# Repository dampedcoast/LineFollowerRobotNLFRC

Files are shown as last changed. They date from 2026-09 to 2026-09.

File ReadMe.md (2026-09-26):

# PD Line Follower — ESP32-S3 · XLine 16 · N20

A competition line-following robot built on an **ESP32-S3**, an **XLine 16** analog IR sensor
array and two **N20 gear motors 5volts 1000 RPM** with tb6612 motor driver. It runs a PD controller with a sensor-driven state machine
for forks, acute tips, 90° corners, zigzags, inverted (white-on-black) zones, line gaps and a
full-black finish pad.

Every tuning parameter can be changed **live over Wi-Fi** from a phone. No reflashing is needed
between runs.

---

## Table of Contents
- [Features](#features)
- [Hardware](#hardware)
- [Wiring](#wiring)
- [Sensor Layout](#sensor-layout)
- [Software Setup](#software-setup)
- [Web Tuner](#web-tuner)
- [First-Run Calibration](#first-run-calibration)
- [How It Works](#how-it-works)
- [Telemetry States](#telemetry-states)
- [Parameter Reference](#parameter-reference)
- [Tuning Guide](#tuning-guide)
- [Troubleshooting](#troubleshooting)
- [Revision History](#revision-history)
- [License](#license)

---

## Features

- **PD steering** on a squared-weight centroid, measured in channel units (error −7 … +7)
- **Straight-line boost**: extra speed when centered, normal speed while correcting
- **Error-hold**: keeps steering with the last correction when the line slides off the side
- **Edge-latch routing**: the outer sensors detect a branch *before* the line is lost, then the
  robot pivots toward the latched side (acute tips, diodes, 90° corners)
- **Sticky Y-bias**: wide clusters commit to one edge until the line narrows again
- **Fork selection** with position continuity (ignores far-away line jumps)
- **Inverted-zone detection**: automatic polarity flip on entry and exit
- **Zone-gap window**: after leaving an inverted zone, a missing line triggers a forward probe instead of reversing
- **Lost-line recovery**: forward gap probe, then reverse until the center sensor is on the line, then spin at the vertex
- **Zigzag mode**: detects rapid alternating corners and drops the base speed
- **Kick-start** on motor direction changes to overcome N20 static friction
- **Full-black finish pad** detection with automatic stop
- **Live web UI** with a sensor bar, state, polarity, edge latches, PWM output and loop timing

---

## Hardware

| Component | Details |
|---|---|
| MCU | ESP32-S3 dev board |
| Line sensor | XLine 16 IR array: 16 channels behind a 16:1 analog multiplexer (S0–S3 select, one analog output) |
| Motors | 2 × N20 micro gear motors (`5 volts 1000 RPM`) |
| Motor driver | tb6612 drive motor driver |
| Power | 12 Volts Lipo 1300mAH with a buck converter for a 5volts output |
| Start button | Momentary push button to GND (uses the internal pull-up) |

---

## Wiring

### Motor driver

| Driver pin | ESP32-S3 GPIO | Function |
|---|---|---|
| IN1 | 6 | Left motor direction A |
| IN2 | 7 | Left motor direction B |
| ENA | 9 | Left motor PWM (1 kHz, 8-bit) |
| IN3 | 4 | Right motor direction A |
| IN4 | 5 | Right motor direction B |
| ENB | 8 | Right motor PWM (1 kHz, 8-bit) |

> If a motor spins backwards, swap its two motor wires on the driver output. There is no need to change the code.

### XLine 16 sensor

| XLine 16 pin | ESP32-S3 GPIO | Function |
|---|---|---|
| S0 | 10 | Mux select bit 0 |
| S1 | 11 | Mux select bit 1 |
| S2 | 12 | Mux select bit 2 |
| S3 | 13 | Mux select bit 3 |
| SIG / OUT | 2 | Analog output (ADC, 11 dB attenuation, 0–4095) |
| VCC / GND | 3V3 / GND | Power |

### Other

| Part | GPIO |
|---|---|
| Start/stop button | 1 (to GND, `INPUT_PULLUP`) |

---

## Sensor Layout

```
        LEFT                                        RIGHT
  [14][13][12][11][10][ 9][ 8][ 7][ 6][ 5][ 4][ 3][ 2][ 1][ 0]
   ^^^^^^                                              ^^^^^^
   left edge zone                                right edge zone
                         center = 7.0

  CH15 = center / pivot-axis sensor (read separately)
```

- Channels **0–14** form the tracking bar. **Index 0 is the rightmost** and 14 is the leftmost.
- `error > 0` means the line is to the **left**.
- The outer `EDGE_ZONE` channels on each side act as edge-latch detectors. **Keep all 15 active.**
- **CH15** sits at the robot's pivot axis. Lost-line recovery reverses until CH15 is on the
  line, so the recovery spin happens exactly at the vertex of an acute tip.

---

## Software Setup

1. Install the **Arduino IDE** (2.x recommended).
2. Add the **ESP32 board package, version 3.x**. The code uses the 3.x `ledcAttach()` API and will not compile on 2.x.
3. Select your ESP32-S3 board and port.
4. Open `line_follower/line_follower.ino` and upload.

No external libraries are needed. `WiFi.h` and `WebServer.h` ship with the ESP32 core.

---

## Web Tuner

1. Power on the robot.
2. Connect your phone or laptop to Wi-Fi **`LineFollower`** (password `12345678`).
3. Open **http://192.168.4.1**.

The page refreshes every 300 ms and shows:

| Field | Meaning |
|---|---|
| Sensor bar | `B` = on the line, `W` = background (polarity-aware) |
| State | Current control state (see [Telemetry States](#telemetry-states)) |
| Status | ON LINE / LOST / FINISHED |
| Polarity | normal / INVERTED |
| Line count / clusters | Active channels / significant clusters |
| Max cluster width | Widest cluster in channels |
| Edge latch L/R | Currently latched branch sides |
| Route side / event | Side the router will pick, and whether a fork event is locked |
| Track pos | Current tracked line position (0–14) |
| Center CH15 | Pivot-axis sensor state |
| Error / Corr | PD error and correction |
| L / R PWM | Motor commands (−255 … 255) |
| Loop µs (max) | Control loop timing |

Every parameter has an input box. Changes apply **immediately** but are **not saved to flash**.
They reset to the code defaults on reboot, so copy any good values back into the code.

Press **START** on the page or the physical button to run or stop. Each start resets all runtime state.

---

## First-Run Calibration

Do these on the actual mat before the first timed run:

1. **`THRESHOLD` / `NOISE`**: place the bar over white, then over the black line, and read
   the raw values. Set `THRESHOLD` between them and `NOISE` just above the white reading.
2. **`INV_WHITE`**: park the bar **inside an inverted zone** and read the raw values of the white line
   on black. Set `INV_WHITE` between the white-line and black-background readings.
3. **Direction check**: run slowly (`base` ≈ 80) and confirm that a line on the left makes the robot
   turn left. If it turns the wrong way, swap the motor wires. Do not flip signs in the code.
4. **`Y_SIDE`**: set the default fork preference (1 = left, 2 = right, 0 = nearest).

---

## How It Works

Each loop (about 4 ms plus sensor read time), `control()` runs through these stages in priority
order. The first stage that takes control returns.

| # | Stage | What it does |
|---|---|---|
| 0 | Edge scan | Every cycle: latches a side if an outer edge sensor sees line while the main line is centered |
| 1 | Black-back | Reverses off the finish pad (only if `FULL_BLACK_STOP = 0`) |
| 2 | Inverted probe | After an all-line event, drives straight to decide between a zone entry and the finish pad |
| 3 | Pivot | Continues an in-place corner pivot until the line is near center |
| 4 | Edge turn | Continues a latched-side pivot until the line overshoots center, then hands back to PD |
| 5 | All-line | Crossing blip (`XING`), or confirmed zone entry/exit (`INV?` / `INV-OUT`) |
| 6 | Edge-turn trigger | Line lost with a fresh latch: start an edge turn |
| 7 | Line lost | Zone-gap probe → error-hold → gap probe → reverse to vertex → spin search |
| 8 | Target selection | Chooses a cluster by continuity, fork side, or sticky Y-bias edge |
| 9 | Pivot entry | A large error starts a corner pivot and counts toward zigzag mode |
| 10 | PD | `corr = Kp·e + Kd·(e − e_last)`, with boost and a reverse limit |

### Routing priority (which way to turn)

1. **Zone-gap window active**: no turn, drive forward
2. **Freshest edge latch**: the side that was just seen branching
3. **Event-held side**: the side locked when the fork event opened
4. **`Y_SIDE`** fallback, or the last-seen line position during spin recovery

There is no hardcoded turn sequence. Every routing decision comes from the sensors.

---

## Telemetry States

| State | Meaning |
|---|---|
| `stopped` | Not running |
| `PD` / `PD-ZZ` | Normal tracking / tracking in zigzag mode |
| `FORK` | Two candidate lines, picking by route side |
| `Y-BIAS` | Hugging one edge of a wide cluster |
| `SNAP-TURN` | Both lines visible with center on: boosted gains |
| `CORNER_L/R`, `ZZ_L/R` | In-place pivot (normal / zigzag) |
| `EDGE_L/R` | Edge-latch turn in progress |
| `XING` | Crossing or checkpoint bar being ridden through |
| `INV?` | All-line confirmed, probing: zone or finish? |
| `INV-IN` | Entered an inverted zone |
| `INV-OUT` | Left an inverted zone |
| `ZONE-GAP` | Expected gap after a zone exit, driving forward |
| `ERR-HOLD` | Line slid off the side, holding the last correction |
| `GAP-FWD` | Centered line vanished, probing forward for a gap |
| `LOST-BACK` | Reversing until CH15 finds the line |
| `LOST-SPIN` / `LOST-FWD` | Spinning / creeping forward to reacquire |
| `BLACK-BACK` | Reversing off the finish pad |
| `FINISH` | Finish pad confirmed, motors stopped |

---

## Parameter Reference

All parameters are live-tunable from the web UI. Distances and positions are in **channel units** (0–14).

### PD and speed
| Param | Default | Description |
|---|---|---|
| `Kp` | 40.0 | Proportional gain |
| `Kd` | 165.0 | Derivative gain |
| `base` | 150 | Base PWM |
| `BOOST_XP` | 30 | Extra PWM when centered (0 = off) |
| `BOOST_BAND` | 0.5 | Error range that counts as centered |
| `SPEED_LIMIT` | 255 | Maximum forward PWM |
| `MAX_REVERSE` | 255 | Maximum reverse PWM (scaled with the effective base) |
| `ERR_HOLD_MS` | 250 | How long to hold the last correction after a side loss |

### Sensors
| Param | Default | Description |
|---|---|---|
| `THRESHOLD` | 1800 | Raw value above which a channel is on the black line |
| `NOISE` | 1000 | Raw floor subtracted before weighting |
| `MUX_SETTLE_US` | 60 | Settling delay after switching mux channels |

### Pivot and zigzag
| Param | Default | Description |
|---|---|---|
| `PIVOT_THRESHOLD` | 5.0 | Error that triggers an in-place pivot |
| `PIVOT_SPEED` | 90 | Pivot PWM |
| `PIVOT_TIMEOUT_MS` | 900 | Pivot give-up time |
| `ZZ_BASE` | 110 | Base PWM in zigzag mode |
| `ZZ_TRIGGER` | 2 | Corners within the window that enable zigzag mode |
| `ZZ_WINDOW_MS` | 150 | Corner-streak window |
| `ZZ_EXIT_MS` | 75 | Leave zigzag mode after this long without a corner |
| `ZZ_CENTER_MS` | 75 | …or after this long centered |

### Inverted zones and crossings
| Param | Default | Description |
|---|---|---|
| `INV_WHITE` | 1800 | Raw value below which a channel is on the white line (inverted). **Calibrate on the mat** |
| `XING_MIN` | 8 | Active channels that count as all-line |
| `INV_CONFIRM_MS` | 280 | All-line dwell time before treating it as a zone or pad (not a crossing) |
| `XING_SPEED` | 75 | PWM while crossing or probing |
| `XING_GAIN` | 1.0 | Steering gain multiplier while crossing |
| `INV_PROBE_MS` | 800 | Probe time to decide between zone and finish |

### Routing and clusters
| Param | Default | Description |
|---|---|---|
| `Y_SIDE` | 1 | Fallback fork side: 1 = left, 2 = right, 0 = nearest |
| `Y_MIN` | 4 | Cluster width that arms the sticky Y-bias |
| `Y_EXIT_W` | 3 | Width at or below which Y-bias starts releasing |
| `Y_EXIT_MS` | 125 | Narrow time needed to release Y-bias |
| `SIGN_GAIN` | 0.6 | PD gain multiplier in fork and Y-bias modes |
| `SIGN_CONFIRM_MS` | 50 | Wide time needed to latch Y-bias |
| `SIGN_MIN_FRAC` | 0.12 | Minimum weight fraction for a cluster to count |
| `JUMP_MAX` | 6.0 | Maximum position jump accepted as the same line |
| `TURN_COOLDOWN_MS` | 125 | How long a fork event keeps its side locked |
| `DIR_SWAP` | 0 | 1 = mirror all routed directions |

### Edge latch
| Param | Default | Description |
|---|---|---|
| `EDGE_ZONE` | 2 | Outer channels per side used as edge detectors (1–4) |
| `EDGE_CONFIRM_MS` | 100 | Debounce time before latching |
| `EDGE_HOLD_MS` | 200 | How long a latch stays valid |
| `EDGE_TURN_SPEED` | 80 | Edge-turn pivot PWM |
| `EDGE_TURN_MS` | 200 | Edge-turn timeout, after which the vertex spin takes over |
| `EDGE_BLANK_MS` | 60 | Blind time at the start of a turn |
| `EDGE_EXIT_POS` | 0.25 | Overshoot past center required to exit the turn |
| `EDGE_SWAP` | 0 | 1 = mirror the edge-turn direction only |

### Lost-line recovery
| Param | Default | Description |
|---|---|---|
| `GAP_FWD_MS` | 250 | Forward probe time for a centered gap |
| `GAP_SPEED` | 80 | PWM for probing and reversing |
| `GAP_EXPECT_MS` | 800 | Zone-gap window after an inverted-zone exit |
| `LOST_BACK_MS` | 900 | Maximum reverse time looking for CH15 |
| `SPIN_BLANK_MS` | 225 | Blind time at the start of a spin |
| `SPIN_SPEED` | 90 | Spin PWM |
| `SPIN_360_MS` | 2500 | Spin duration before a forward creep |
| `SEARCH_FWD_MS` | 300 | Forward creep between spins |

### Motor kick and finish
| Param | Default | Description |
|---|---|---|
| `KICK_PWM` | 220 | PWM burst on a direction change (helps N20 static friction) |
| `KICK_MS` | 60 | Burst duration |
| `KICK_MIN_CMD` | 60 | Minimum command that triggers a kick |
| `FULL_BLACK_STOP` | 1 | 1 = stop on the finish pad, 0 = back off it |
| `FULL_BLACK_BACK_MS` | 400 | Back-off time when not stopping |

---

## Tuning Guide

1. **Start slow**: `base` ≈ 100, `BOOST_XP` = 0. Tune `Kp` until the robot follows curves without
   oscillating, then raise `Kd` to damp the wobble.
2. **Raise speed** in steps of about 10, re-tuning `Kd` each time. Enable `BOOST_XP` once straights are stable.
3. **Corners**: if the robot overshoots 90° turns, lower `PIVOT_THRESHOLD` or `PIVOT_SPEED`.
4. **Forks and tips**: watch *Edge latch L/R* on the UI while pushing the robot through by hand.
   Latches should appear just before the branch. Adjust `EDGE_CONFIRM_MS` or `EDGE_ZONE`.

**Author:** Yazan Abubakir

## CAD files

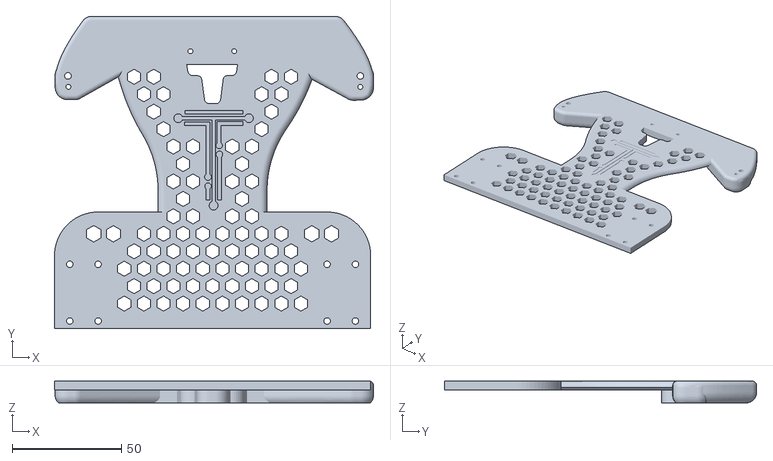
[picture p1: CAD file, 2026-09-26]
CAD/Line Follower Robot For Sale 2.stl
146.3 x 143.2 x 10.0

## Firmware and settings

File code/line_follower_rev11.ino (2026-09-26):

// ====== PD Line Follower — ESP32-S3 + H-bridge + 15ch analog IR ============
// corr = Kp*error + Kd*(error - lastError), signed drive, non-blocking pivot.
//
// ============================================================================
// [rev11] — DAY-2 ARENA DECODED (vector-PDF analysis) + ZONE-GAP CONCEPT
// ============================================================================
//   ARENA FACTS (measured programmatically from DAY_2_ARENA_V_2 PDF):
//     * The sheet holds TWO PRINTS OF THE SAME 3m x 3m LAYOUT, rotated 180
//       degrees to each other (raster match 99.85%). A 180-deg rotation
//       PRESERVES HANDEDNESS: driving START->END, left turns stay left
//       turns on either print -> ONE tune covers both. DIR_SWAP stays 0,
//       Y_SIDE / EDGE_SWAP are identical on both prints.
//     * Line width 17 mm, same as day 1. The START straight runs through
//       giant "NLFRC" letter glyphs that act as crossbars / short branches
//       (same family as the day-1 start bar + cathode bars -> XING /
//       edge-latch already cover them).
//     * TWO REAL INVERTED WHITE-ON-BLACK ZONES on the route (day 1: none):
//         Z1 "freeform": large black region (local thickness up to 350 mm)
//            with a WHITE curved Y-fork figure inside.
//         Z2 "grid": two 275x749 mm black slabs, a 17 mm white channel
//            between them, crossed by a 63 mm white band -> a white
//            hourglass + crossbar figure (forks INSIDE the zone).
//     * ONE LINE BREAK: an ~8-20 mm white stand-off where the black line
//       stops short of Z1's edge. In addition, EVERY zone exit dumps the
//       bot onto plain white until the black line resumes -> zone exits
//       BEHAVE LIKE LINE GAPS.
//     * 5 CHECKPOINT BARS (180x17 mm, red square alongside) cross the
//       line: full-bar blip for a few ms -> XING state rides through,
//       edge-latch GUARD 1 suppresses latching. No handling needed.
//     * Shared 250 mm FULL-BLACK END PAD between the two prints ->
//       FULL_BLACK_STOP confirmed correct (all-line -> probe -> FINISH,
//       and running off the pad during the probe finishes immediately
//       because plain white reads all-line in inverted polarity).
//
//   TUNE CHANGES vs rev10 defaults (all remain live web knobs):
//     * Y_MIN 2 -> 4  (MANDATORY): arms the GAP-FWD forward probe. With
//       Y_MIN=2 a plain 2ch line keeps biasHold latched, every loss is
//       marked "tip likely" and the bot REVERSES — at a zone exit that
//       reverses it back INTO the zone, and it hard-fails the Z1 line
//       break. Diode tips still latch Y-bias: tips widen to 4ch (day-1
//       calibration), exactly at the new threshold.
//     * XING_MIN 8 -> 10: kills the ring-trunk XING/INV? flicker (trunk
//       reads 7-8ch) that rev10 flagged, while zone entries, checkpoint
//       bars and the END pad light the full bar (15ch) with margin.
//     * INV_CONFIRM_MS 180 -> 280: inside Z2 the 63 mm white cross-band
//       dwells > 180 ms under ~0.35 m/s and would false-fire INV-OUT
//       mid-zone. 280 clears the band; the 17 mm checkpoint bars (few ms
//       dwell) and real zone faces are unaffected.
//     * INV_WHITE 1800: CALIBRATE ON THE MAT — park the bar inside a
//       zone, read raws off the web UI before the first run.
//     * EDGE_HOLD_MS stays 200: stub/comb features exist on this track
//       too; short expiry is still what prevents stale-latch hijacks.
//
//   NEW CONCEPT — ZONE-GAP WINDOW (GAP_EXPECT_MS, default 700):
//     * INV-OUT arms a timer. While it runs, a lost line goes STRAIGHT to
//       the forward probe, unconditionally — overriding the inEvent /
//       biasHold "tip likely" veto — because right after a zone exit the
//       line is EXPECTED to be missing (white stand-off before the black
//       line resumes). Without this, the event side-lock (kept alive
//       during losses by design) could reverse the bot back into the
//       zone it just left. Edge latches are cleared at INV-OUT too, so a
//       stale slab-edge latch can't hijack the exit.
//   Resolved from rev10's open questions: line gaps DO exist -> Y_MIN=4
//   locked in; XING_MIN raised as pre-planned; no mandatory right-only T
//   found on this layout -> EDGE_SWAP stays 0 unless the mat says otherwise.
//
// ============================================================================
// [rev10] — DAY-2 BUILD: field-validated tune locked in, nothing hardcoded
// ============================================================================
//   * All tuning defaults below are the DAY-1 VALIDATED set (ran the NLFRC
//     mat). The rev9 WARNING flags on Y_MIN / EDGE_TURN_MS / EDGE_CONFIRM_MS
//     / EDGE_HOLD_MS are downgraded to notes — track results beat theory.
//     Short EDGE_HOLD (200) is correct for this mat: the dead-end stub comb
//     arms edge latches constantly, and fast expiry stops a stale stub
//     latch from hijacking a later turn.
//   * PIVOT_TIMEOUT_MS added to the web UI (was the last non-tunable knob).
//   * ZERO track-specific routing: no TURN_SEQ, no slot tables, no lap
//     counting. Every routed decision is sensor-driven (freshest edge latch
//     wins); Y_SIDE is the only preference fallback — itself a live knob.
//
//   MAT COVERAGE (START -> END, rev11 updated for the day-2 layout):
//     start bar + "NLFRC" letter crossbars  -> XING blip / edge-latch turns
//     long straights                        -> PD + BOOST_XP in BOOST_BAND
//     freeform inverted zone Z1 (white Y)   -> all-line confirm -> INV-IN,
//                                              fork inside via edge/Y_SIDE
//     line break at Z1 edge                 -> ZONE-GAP / GAP-FWD probe
//     circled-triangle "hazard" symbols     -> Y-BIAS hug + edge-latch turn
//     checkpoint bars (x5)                  -> XING blip, no latch (guard)
//     grid inverted zone Z2 (hourglass)     -> INV-IN, ride the channel,
//                                              INV_CONFIRM_MS=280 rides the
//                                              63mm white cross-band
//     zone exits onto white                 -> INV-OUT + ZONE-GAP window
//     ring cluster ("grapes")               -> wide-cluster Y-BIAS edge hug,
//                                              XING_MIN=10 stops flicker
//     dead-end stub comb                    -> straight through (latch
//                                              expires, line never lost)
//     sawtooth zigzag                       -> pivots + ZZ mode (base drop)
//     square-wave staircase                 -> pivot / edge turn / ERR-HOLD
//     S-waves / serpentine coils / loops    -> PD; self-crossing = XING or
//                                              nearest-cluster continuity
//     END pad (250mm, shared)               -> all-line confirm -> probe ->
//                                              FULL_BLACK_STOP
//
//   DAY-2 LIVE-TUNE NOTES (web UI, no reflash):
//     * If XING/INV? still flickers in the rings on SLOW runs, raise
//       XING_MIN to 11-12 — entries/pad light all 15, huge margin.
//     * If the bot false-toggles INV-OUT inside Z2 (watch Polarity on the
//       UI), raise INV_CONFIRM_MS toward 350 — or keep speed up in-zone.
//     * If a zone exit still reverses, raise GAP_EXPECT_MS to 1000.
//     * Both prints are the same course: tune once, run either.
//
// ============================================================================
// [rev9] — HARDCODED TURNS REMOVED, ROUTING IS FULLY EDGE-DRIVEN
// ============================================================================
//   * TURN_SEQ (the 12-slot hardcoded direction table) is DELETED. Every
//     routed decision now comes from the EDGE-LATCH concept:
//       - fork target selection      -> freshest edge latch side
//       - sticky Y-BIAS edge choice  -> freshest edge latch side
//       - edge-turn direction        -> the latched side itself
//       - fallback spin direction    -> latched side held by the event
//     Only when NO latch exists does routing fall back to Y_SIDE.
//   * TURN_COOLDOWN_MS still exists but now only controls how long an
//     event keeps its chosen side locked (quiet time to expire inEvent).
//
// ============================================================================
// [rev8] ORIGINAL TUNE SCALE (error in CHANNEL units -7..+7) + WINNER
//   CONCEPTS: ERR-HOLD (keep steering with last correction on side loss)
//   and STRAIGHT-LINE BOOST (BOOST_XP when centered).
//
// ============================================================================
// [rev6] — EDGE-LATCH TURN: acute tips, diode, 90-deg corners by EDGE sensors
// ============================================================================
//     1. DETECT+SAVE: while tracking, if an OUTER EDGE sensor (ch 0..EDGE_ZONE-1
//        right side, ch 14..15-EDGE_ZONE left side) reads the line while the
//        MAIN line is still near the center of the bar, that side is LATCHED
//        (debounced EDGE_CONFIRM_MS, remembered EDGE_HOLD_MS). Guards: no
//        latch during XING (all-line) and none if no cluster is near center.
//     2. WAIT: nothing happens while the line is still under the bar; PD
//        keeps aligning with the track.
//     3. TRIGGER: the moment the bar LOSES the line with a fresh latch ->
//        EDGE-TURN starts instead of blind recovery.
//     4. TURN: the motor on the LATCHED side reverses, the other drives
//        forward -> in-place pivot toward the saved branch.
//     5. EXIT: keep rotating (EDGE_BLANK_MS blind at start) until a cluster
//        shows PAST CENTER on the OPPOSITE half (EDGE_EXIT_POS overshoot);
//        lastError is seeded so PD immediately corrects back and keeps
//        aligning with the track.
//     6. SAFETY: EDGE_TURN_MS timeout -> vertex-spin recovery.
//   DIR_SWAP mirrors ALL routed directions; EDGE_SWAP mirrors only the
//   edge-turn direction — both live-tunable.
//
//   LOST-LINE ROTATION DIRECTION (priority order):
//     0. ZONE-GAP window active -> no rotation, forward probe (rev11)
//     1. edge latch side (this concept)
//     2. event-held side (the latch that opened the event)
//     3. lastPos heuristic: spins toward the side the line was last seen
//
// ============================================================================
// CALIBRATION FINDINGS (serial tool, day-1 track — geometry family matches):
//   * Diode entry & acute angles present as ONE cluster that widens to a
//     MEASURED MAX WIDTH OF 4 channels.
//   * Circle/stop-sign trunk reads 7-8 channels wide.
//   * BROWNOUT_RST seen during logging -> power the logic rail from battery.
//
// TRACK-FAILURE FIXES (marked points):
//   [BOX] INV_PROBE_MS 400 -> 800; INV-IN locks the cluster NEAREST CENTER.
//   [SPIKE] LOST-BACK reverses until CH15 (sensor AT the pivot axis) is on
//     the line, so the fallback spin happens AT the vertex.
//   [XING] INV_CONFIRM_MS above crossing dwell time (perpendicular line).
//
// STICKY Y-BIAS: wide cluster (width>=Y_MIN for SIGN_CONFIRM_MS) latches
//   the chosen edge until width <= Y_EXIT_W for Y_EXIT_MS.
//
// SENSOR WIRING: index 0=RIGHTMOST, 14=LEFTMOST. error>0 = line LEFT.
// WEB TUNING: WiFi "LineFollower" (pass 12345678) -> http://192.168.4.1

#include <WiFi.h>
#include <WebServer.h>

#define IN1 6
#define IN2 7
#define IN3 4
#define IN4 5
#define ENA 9
#define ENB 8

#define S0  10
#define S1  11
#define S2  12
#define S3  13
#define OUT2 2

#define button 1

int THRESHOLD = 1800;
int NOISE     = 1000;

// ALL 15 bar sensors active — the outer channels ARE the edge-latch
// detectors. Never drop them on this track.
const int order[15] = {0,1,2,3,4,5,6,7,8,9,10,11,12,13,14};
#define CENTER_CH 15
#define MAXC 4

// sticky-bias release
int Y_EXIT_W  = 3;    // day-1 validated (release width; see Y_MIN note)
int Y_EXIT_MS = 125;

// acute-tip fallback recovery geometry
int LOST_BACK_MS  = 900;
int SPIN_BLANK_MS = 225;

int raw[16];

// ====== TUNABLE PARAMS (rev11: day-2 arena-confirmed set) ===================
float Kp              = 40.0;
float Kd              = 165.0;
int   base            = 150;
int   BOOST_XP        = 30;    // straight-line speed boost (0 = off)
float BOOST_BAND      = 0.5;   // |error| <= this counts as centered (ch)
int   SPEED_LIMIT     = 255;
int   ERR_HOLD_MS     = 250;
float PIVOT_THRESHOLD = 5.0;   // channel units
int   PIVOT_SPEED     = 90;
int   MAX_REVERSE     = 255;
int   SPIN_SPEED      = 90;
int   MUX_SETTLE_US   = 60;

// zigzag
int           ZZ_BASE      = 110;
int           ZZ_TRIGGER   = 2;
unsigned long ZZ_WINDOW_MS = 150;
unsigned long ZZ_EXIT_MS   = 75;
int           ZZ_CENTER_MS = 75;

// inverted + intersections
int   INV_WHITE      = 1800;   // CALIBRATE ON THE MAT before run 1: park the
                               // bar inside an inverted zone, read raws.
int   XING_MIN       = 8;     // rev11: was 8. Ring trunk reads 7-8ch and
                               // flickered XING/INV? on slow runs; zone
                               // faces / checkpoint bars / END pad light
                               // the full 15ch. Raise to 11-12 live if the
                               // rings still flicker.
int   INV_CONFIRM_MS = 280;    // rev11: was 180. Z2's 63mm white cross-band
                               // dwells >180ms below ~0.35 m/s and would
                               // false-fire INV-OUT mid-zone. Checkpoint
                               // bars (17mm) are still far below this.
int   XING_SPEED     = 75;
float XING_GAIN      = 1.0;
int   INV_PROBE_MS   = 800;

// routing / clusters (channel units)
int   Y_SIDE          = 1;     // fallback ONLY when no edge latch exists.
                               // Same value works on BOTH prints (180-deg
                               // rotation preserves handedness).
int   Y_MIN           = 4;     // rev11: was 2 — MANDATORY for this arena.
                               // The track has a real line break at Z1 and
                               // every inverted-zone exit behaves like a
                               // gap; Y_MIN=2 kept biasHold latched on a
                               // plain 2ch line, flagged losses "tip
                               // likely" and skipped GAP-FWD (reversed —
                               // straight back into the zone). Diode tips
                               // widen to 4ch (day-1 calib) so tips still
                               // latch Y-bias at exactly this threshold.
float SIGN_GAIN       = 0.6;
int   SIGN_CONFIRM_MS = 50;
float SIGN_MIN_FRAC   = 0.12;
float JUMP_MAX        = 6.0;n

// ---- EDGE-LATCH TURN --------------------------------------------------------
int   EDGE_ZONE       = 2;
int   EDGE_CONFIRM_MS = 100;   // day-1 validated
int   EDGE_HOLD_MS    = 200;   // day-1 validated — short expiry is what
                               // keeps the stub comb from leaving stale
                               // latches. Day-2 layout has combs too: keep.
int   EDGE_TURN_SPEED = 80;
int   EDGE_TURN_MS    = 200;   // day-1 validated — acts as a directional
                               // kick; the vertex spin finishes the turn.
int   EDGE_BLANK_MS   = 60;
float EDGE_EXIT_POS   = 0.25;
int   EDGE_SWAP       = 0;     // 1 = mirror the edge-turn direction only.
                               // No mandatory right-only T found on the
                               // day-2 layout; leave 0 unless the mat says
                               // otherwise. Same value on both prints.
int   DIR_SWAP        = 0;     // 1 = mirror ALL routed directions. NOT
                               // needed between the two prints (rotation,
                               // not mirror). Keep 0.

// rev9: event side-lock quiet time (formerly the TURN_SEQ cooldown)
unsigned long TURN_COOLDOWN_MS = 125;

// lost-line search cycle
int   GAP_FWD_MS     = 250;
int   GAP_SPEED      = 80;
int   GAP_EXPECT_MS  = 800;    // rev11 ZONE-GAP: window armed at INV-OUT
                               // during which a lost line forces the
                               // forward probe (overrides inEvent/biasHold
                               // "tip likely"). Raise to 1000 live if a
                               // zone exit still reverses.
int   SPIN_360_MS    = 2500;
int   SEARCH_FWD_MS  = 300;

// kick-start
int   KICK_PWM       = 220;
int   KICK_MS        = 60;
int   KICK_MIN_CMD   = 60;

// finish behavior
bool  FULL_BLACK_STOP    = true;
int   FULL_BLACK_BACK_MS = 400;
// ============================================================================

unsigned long PIVOT_TIMEOUT_MS = 900;   // rev10: now web-tunable

// ===== runtime state =====
float lastError = 0;
float heldErr   = 0;      // winner error-hold memory (channel units)
float lastPos   = 7.0;
float trackPos  = 7.0;
bool  running   = false;
bool  centerHit = false;
bool  lastButton = HIGH;
unsigned long lastButtonMs = 0;
unsigned long lastCornerMs = 0;
int   cornerStreak = 0;
bool  zigzagMode   = false;
bool  inverted     = false;

int   lineCount = 0;
int   nSig      = 0;
float sigPos[MAXC];
int   sigLo[MAXC], sigHi[MAXC];

int   ctlMode = 0;                   // 0=PD/track 1=FORK 2=Y-BIAS
bool  pivotActive = false;
bool  pivotLeft   = false;
unsigned long pivotUntil = 0;
int   pivotFails  = 0;
unsigned long blackBackUntil = 0;
unsigned long invProbeUntil  = 0;

unsigned long wideSince      = 0;
unsigned long allLineSince   = 0;
unsigned long lostSince      = 0;
unsigned long spinStart      = 0;
unsigned long centerOnSince  = 0;

// ---- committed lost-recovery runtime ----
bool          recoverLock    = false;
unsigned long spinBlankUntil = 0;

// ---- rev11 ZONE-GAP runtime ----
unsigned long gapExpectUntil = 0;

// ---- sticky Y-BIAS runtime ----
bool          biasHold    = false;
unsigned long narrowSince = 0;

// ---- rev9: event runtime (side lock, no sequence) ----
bool          inEvent       = false;
int           activeSide    = 0;
unsigned long eventLastSeen = 0;

// ---- edge-latch runtime ----
unsigned long edgeLseen  = 0;
unsigned long edgeRseen  = 0;
unsigned long edgeLlatch = 0;
unsigned long edgeRlatch = 0;
bool          edgeTurnActive = false;
bool          edgeTurnLeft   = false;
unsigned long edgeTurnStart  = 0;
unsigned long edgeTurnBlank  = 0;

// ===== telemetry =====
char   bar[16];
float  t_pos = 7.0, t_err = 0, t_corr = 0;
int    t_L = 0, t_R = 0;
int    t_wmax = 0;
bool   t_online = true;
String t_state  = "idle";
unsigned long loopUs = 0, loopMaxUs = 0;

WebServer server(80);

// ================================================================
int readCh(int ch) {
  digitalWrite(S0,(ch>>0)&1); digitalWrite(S1,(ch>>1)&1);
  digitalWrite(S2,(ch>>2)&1); digitalWrite(S3,(ch>>3)&1);
  delayMicroseconds(MUX_SETTLE_US);
  return analogRead(OUT2);
}

void readSensors() {
  double wsum = 0, tot = 0;
  double cw[MAXC] = {}, ct[MAXC] = {};
  int    lo[MAXC], hi[MAXC];
  int    nClu = 0;
  lineCount = 0;
  int gapRun = 100;

  for (int i = 0; i < 15; i++) {
    int ch = order[i];
    raw[ch] = readCh(ch);

    bool   isLine;
    double w = 0;
    if (!inverted) {
      isLine = (raw[ch] > THRESHOLD);
      if (raw[ch] > NOISE) w = (double)(raw[ch] - NOISE);
    } else {
      isLine = (raw[ch] < INV_WHITE);
      if (raw[ch] < INV_WHITE) w = (double)(INV_WHITE - raw[ch]);
    }

    bar[i] = isLine ? 'B' : 'W';
    if (isLine) lineCount++;

    if (w > 0) {
      if (gapRun >= 2 && nClu < MAXC) { lo[nClu] = i; hi[nClu] = i; nClu++; }
      gapRun = 0;
      int c = nClu - 1;
      if (c >= 0) {
        hi[c] = i;
        double w2 = w * w;
        cw[c] += w2 * i;  ct[c] += w2;
        wsum  += w2 * i;  tot   += w2;
      }
    } else {
      gapRun++;
    }
  }
  bar[15] = '\0';

  nSig = 0;
  for (int c = 0; c < nClu; c++) {
    if (tot > 0 && ct[c] >= (double)SIGN_MIN_FRAC * tot) {
      sigPos[nSig] = (ct[c] > 0) ? (float)(cw[c] / ct[c]) : 7.0f;
      sigLo[nSig]  = lo[c];
      sigHi[nSig]  = hi[c];
      nSig++;
    }
  }

  t_wmax = 0;
  for (int c = 0; c < nSig; c++) {
    int w = sigHi[c] - sigLo[c] + 1;
    if (w > t_wmax) t_wmax = w;
  }

  raw[CENTER_CH] = readCh(CENTER_CH);
  centerHit = inverted ? (raw[CENTER_CH] < INV_WHITE)
                       : (raw[CENTER_CH] > THRESHOLD);
  if (centerHit) { if (centerOnSince == 0) centerOnSince = millis(); }
  else             centerOnSince = 0;

  t_online = (tot > 0);
  if (t_online) t_pos = (float)(wsum / tot);
}

// ================================================================
// mirror helper. 1=LEFT 2=RIGHT 0=nearest.
int applyDirSwap(int s) {
  if (!DIR_SWAP) return s;
  return (s == 1) ? 2 : (s == 2) ? 1 : 0;
}

// rev9: SENSOR-DRIVEN ROUTING — the freshest edge latch decides the side.
// No latch -> Y_SIDE fallback. (Replaces the hardcoded TURN_SEQ table.)
int liveSide() {
  unsigned long now = millis();
  bool L = (edgeLlatch != 0) && (now - edgeLlatch <= (unsigned long)EDGE_HOLD_MS);
  bool R = (edgeRlatch != 0) && (now - edgeRlatch <= (unsigned long)EDGE_HOLD_MS);
  if (L && R) return (edgeLlatch >= edgeRlatch) ? 1 : 2;  // newer latch wins
  if (L) return 1;
  if (R) return 2;
  return Y_SIDE;
}

int routeSide() {
  if (inEvent) return activeSide;          // side locked for this event
  return applyDirSwap(liveSide());
}
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
void loop() {
  unsigned long t0 = micros();
  server.handleClient();
  readSensors();

  bool b = digitalRead(button);
  if (b == LOW && lastButton == HIGH && millis() - lastButtonMs > 250) {
    running = !running;
    if (!running) stopMotors();
    resetState();
    lastButtonMs = millis();
  }
  lastButton = b;

  if (running) control();
  else { stopMotors(); t_state = "stopped"; }

  loopUs = micros() - t0;
  if (loopUs > loopMaxUs) loopMaxUs = loopUs;
  delay(4);
}
